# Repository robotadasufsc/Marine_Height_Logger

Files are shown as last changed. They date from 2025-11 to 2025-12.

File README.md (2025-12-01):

# 🌊 Marine Height Logger (LidarBox)






**Desenvolvido por:** Robota da UFSC

## 📖 Visão Geral

O **Marine Height Logger** é um instrumento oceanográfico de baixo custo projetado para registrar a variação de altura da superfície da água (ondas e marés). O sistema utiliza tecnologia **LiDAR** para medir a distância até a água, correlacionando esses dados com posicionamento global (**GPS**) e dados inerciais (**IMU**) para compensar o movimento da boia ou embarcação (Heave/Pitch/Roll).

O firmware foi otimizado para alta performance de escrita, utilizando um **buffer de saída** para salvar dados em lotes no cartão SD, minimizando a latência e evitando gargalos de I/O.

---

## 🛠️ Hardware e Eletrônica

### 1. Lista de Componentes (BOM)

| Componente | Modelo | Função | Protocolo |
| :--- | :--- | :--- | :--- |
| **MCU** | Arduino ProMicro (ATmega32u4) | Processamento Central | - |
| **LiDAR** | Benewake TF02-Pro *ou* SF11 | Distância (Altura) | I²C (Endereço `0x10`) |
| **GPS** | GlobalSat EM-506 | Tempo e Posição | Serial (UART) |
| **IMU** | Pololu MinIMU-9 v5 (LSM6) | Acelerômetro/Giroscópio | I²C |
| **Storage** | SparkFun SD Breakout | Datalogging | SPI |
| **Debug** | LED Genérico | Status Visual | Digital (Pino 5) |

> [!WARNING]
> **Atenção com o LiDAR TF02-Pro:** Este sensor vem de fábrica configurado para Serial. É **obrigatório** reconfigurá-lo para I²C (endereço `0x10`) utilizando o software do fabricante antes da montagem final.

### 2. Pinagem (Conexões)

Baseado na versão atual do firmware (`src/main.cc`):

| Periférico | Pinos Módulo | Pino Arduino | Observação |
| :--- | :--- | :--- | :--- |
| **I²C Bus** | SDA / SCL | **D2 / D3** | LiDAR e IMU compartilham este barramento |
| **GPS** | RX / TX | **TX0 / RX1** | Serial Hardware |
| **SD Card** | CS | **D10** | Chip Select |
| **SD Card** | MOSI | **D16** | SPI MOSI |
| **SD Card** | MISO | **D14** | SPI MISO |
| **SD Card** | SCK | **D15** | SPI Clock |
| **LED Debug** | Anodo (+) | **D5** | LED externo de status |

---

## 🚥 Tabela de Diagnóstico (LEDs)

O sistema não possui tela (headless). O status é comunicado através do **LED Externo (Pino 5)** e do **LED RX interno**, que piscam em sincronia.

### ✅ Status Normal
* **10 Piscadas Rápidas:** Boot concluído com sucesso. Todos os sensores foram detectados e o arquivo de log foi criado.
* **Aceso/Piscando durante operação:** Indica atividade de escrita no buffer ou no cartão SD.

### ❌ Códigos de Erro (Loop Infinito)
Se o sistema falhar durante a inicialização, ele entrará em um loop infinito, piscando o código de erro repetidamente (ciclos de 300ms).

| Nº Piscadas | Código Interno | Significado | Solução Provável |
| :---: | :--- | :--- | :--- |
| **2x** | `ERR_NO_LIDAR` | **LiDAR não encontrado** | Verifique cabos I²C (D2/D3) e alimentação (5V). Confirme o endereço `0x10`. |
| **3x** | `ERR_NO_GPS_LOCK` | **Falha de GPS** | O GPS não respondeu aos comandos iniciais ou baud rate incorreto. |
| **4x** | `ERR_IMU_FAIL` | **Falha no IMU** | O acelerômetro (LSM6) não foi detectado no barramento I²C. |
| **5x** | `ERR_SD_FAIL` | **Falha Física no SD** | Cartão não inserido, mal contatado ou formato inválido. |
| **6x** | `ERR_SD_CREATE_FAIL`| **Erro de Arquivo** | Cartão detectado, mas não foi possível criar o arquivo `LOG_xxxx.CSV` (Cartão cheio?). |

---

## 💾 Detalhes do Firmware e Dados

### Arquivos de Log
O sistema cria arquivos sequenciais na raiz do cartão:
* `LOG_0000.CSV`
* `LOG_0001.CSV`
* ...

### Estrutura do CSV
O arquivo contém as seguintes colunas separadas por tabulação ou vírgula:
1. `gmt_date` / `gmt_time` (Data/Hora GPS)
2. `num_sats` (Qualidade do sinal)
3. `longitude` / `latitude` / `altitude`
4. `laser_altitude_cm` (Leitura bruta do LiDAR)
5. `tilt_deg` (Inclinação calculada)
6. `accel_x/y/z` (Dados brutos do acelerômetro)
7. `gyro_x/y/z` (Dados brutos do giroscópio)

### Segurança de Dados (Buffer)
Para economizar tempo de processamento, o sistema mantém os dados em RAM e realiza a escrita física no cartão SD (**flush**) apenas a cada **20 linhas de medição**.

> [!CAUTION]
> **Ao desligar o equipamento:** Após a última atividade intensa do LED, aguarde cerca de 3 a 5 segundos antes de remover a energia. Isso garante que o último bloco de 20 linhas foi salvo corretamente no cartão, evitando corrupção do arquivo.

### Resiliência (Watchdog I²C)
O código implementa `Wire.setWireTimeout(3000, true)`. Isso impede que o microcontrolador trave completamente caso um sensor I²C (como o IMU ou LiDAR) pare de responder ou desconecte durante a operação.

---

## 🚀 Como Compilar e Enviar

Este projeto utiliza **PlatformIO**.

1. **Clone o repositório:**
   ```bash
   git clone [https://github.com/seu-usuario/Marine_Height_Logger.git](https://github.com/seu-usuario/Marine_Height_Logger.git)
   
2. **Instale as dependências (automático via platformio.ini):**

* SD
* TinyGPSPlus
* LSM6 (Pololu)

3. **Compile e faça o upload:**
    ```Bash
    pio run --target upload

---

##📝 Licença

Este projeto está licenciado sob a EPL-2.0.

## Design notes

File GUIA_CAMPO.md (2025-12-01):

# 📋 Guia de Operação em Campo: Marine Height Logger

Este documento contém instruções rápidas para operação, diagnóstico e segurança dos dados durante a utilização do equipamento em campo.

## 1. Checklist Pré-Operação
Antes de lacrar a caixa ou lançar o equipamento:

- [ ] **Cartão SD:** Inserido corretamente e formatado (FAT16/FAT32).
- [ ] **LiDAR:** Lentes limpas (sem sal, poeira ou obstruções).
- [ ] **Parafusos:** Verificar se todos os parafusos e velcro estão firmes.
- [ ] **Bateria:** Carga verificada.

---

## 2. Procedimento de Inicialização

1. **Ligar:** Alterne o botão para ligado.
2. **Aguardar:** O sistema leva alguns segundos para energizar o GPS e sensores.
3. **Confirmação Visual (LED):**Desconecte
   - O sistema deve emitir **10 piscadas rápidas**.
   - **Significado:** Boot OK + Sensores Detectados + Arquivo `.CSV` criado com sucesso.
4. **Aguardando GPS:** O LED piscará a cada 5 segundos esperando a conexão com os satelites, poderá levar de 30 segundos a 3 minutos. passado esse periodo reinicie e tente novamente. para o fix com os satélites tente deixá-lo em um local aberto e com o sensor gps lateral virado para cima.
5. **Operação:** O LED passará a piscar periodicamente(a cada 1 segundo), indicando que o buffer está enchendo e os dados estão sendo processados.

---

## 3. Procedimento de Desligamento (⚠️ CRÍTICO)

> **Risco de Perda de Dados**
> O sistema utiliza um *buffer* de escrita e só salva fisicamente no cartão SD a cada **20 segundos**. Cortar a energia abruptamente pode corromper o arquivo atual.

1. Observe o LED de status (externo).
2. Após uma sequência de piscadas (atividade de escrita).
3. Alterne o botão para desligado com segurança.

---

## 🆘 Diagnóstico de Erros (LED em Loop)

Se o LED entrar em um padrão repetitivo (pisca X vezes, pausa, repete), consulte a tabela abaixo:

| Piscadas | Componente Falho | Ação Corretiva |
| :---: | :--- | :--- |
| **2x** | **LiDAR** | Sensor não detectado. Verifique cabos SDA/SCL e alimentação. Confirme se está no endereço `0x10`. |
| **3x** | **GPS** | GPS não responde. Verifique cabos TX/RX ou se o módulo está queimado. |
| **4x** | **IMU** | Acelerômetro travado. Verifique conexão I²C com o Pololu MinIMU-9. |
| **5x** | **Cartão SD** | Cartão ausente ou mal encaixado no slot. |
| **6x** | **Erro de Arquivo** | Falha ao criar arquivo `LOG_xxxx.CSV`. Cartão pode estar cheio, protegido (trava física) ou corrompido. |

Tentativas de reparo:
* Ligue e desligue o equipamemto algumas vezes dando um intervalo de 1 segundo mínimo entre cada desligameto.
* Tente iniciar o equipamento sem o cartao SD, deixe entrar no loop de erro, desligue, reinsira o cartão e ligue novamente.
* Tente outras combinações desses métodos. 

---

## 📝 Notas Técnicas
* **Arquivos:** O sistema gera nomes sequenciais (`LOG_0000.CSV`, `LOG_0001.CSV`...). Ele **nunca** sobrescreve arquivos antigos.
* **Sinal de GPS:** Em dias nublados ou locais obstruídos, o GPS pode demorar para obter o *Fix*. O sistema gravará `NaN` ou `INVALID` nas colunas de GPS, mas continuará registrando dados do LiDAR e IMU normalmente.
* **Watchdog:** Se um sensor I²C travar durante a operação, o sistema tentará reiniciar o barramento automaticamente após 3 segundos (timeout), evitando o congelamento total do logger.

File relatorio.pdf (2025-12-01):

# 📄Relatório de Melhorias: Marine Height Logger (LidarBox)

Data: Dezembro/2025
Status: Finalizado

# 1. Evolução da Eletrônica e Potência

Para aumentar a estabilidade do sistema e evitar quedas de tensão (brownouts) críticas para a gravação no cartão SD, o sistema de energia foi totalmente reformulado:

Microcontrolador (5V): Substituição do Arduino Pro Micro 3.3V pela versão de 5V. Isso garante níveis lógicos mais estáveis e compatibilidade direta com a maioria dos periféricos, eliminando problemas de conversão de nível lógico.
Gerenciamento de Energia (BMS): Integração de um módulo BMS (Battery Management System) dedicado. Ele gerencia a carga e descarga, protegendo a célula contra sobrecarga, curto-circuito e descarga profunda, além de garantir uma tensão de saída estável para o sistema.
Bateria 18650: Padronização para célula Li-ion 18650. O novo suporte (holder) permite a substituição rápida da bateria em campo sem a necessidade de ferramentas, aumentando a autonomia operacional.

# 2. Sensores e Hardware

Os módulos principais foram atualizados para versões mais eficientes, precisas e compactas:

LiDAR (Benewake TF02): Implementação do sensor Benewake TF02, configurado para comunicação via protocolo I²C. Este modelo oferece maior robustez contra interferência solar e leituras mais estáveis sobre a superfície da água comparado ao modelo anterior.
IMU (MinIMU-9 v6): Atualização para o módulo Pololu MinIMU-9 v6. Este módulo integra sensores de última geração (LSM6DSO para acelerômetro/giroscópio e LIS3MDL para magnetômetro), proporcionando uma precisão superior na compensação de movimentos (tilt/roll) da embarcação ou drone.
GPS (GP-735T): Substituição pelo módulo GP-735T. Escolhido pelo seu fator de forma extremamente compacto e capacidade de aquisição rápida de satélites (Fast Time-to-Fix).
PCB Dedicada: Todo o circuito, anteriormente prototipado em fios, foi migrado para uma Placa de Circuito Impresso (PCB) personalizada. Isso permite a fixação rígida de quase todos os módulos, eliminando a "fiação aérea" e aumentando drasticamente a resistência mecânica contra as vibrações dos drones.

# 3. Mecânica e Interface de Usuário (UX)

A carcaça foi completamente remodelada focando na ergonomia do operador e no feedback visual imediato:

Acoplamento Universal: Novo sistema de fita com velcro de fixação para drones, facilitando o balanceamento do centro de gravidade e garantindo segurança durante o voo.
Display de Bateria: Inclusão de um display dedicado para verificação de tensão da bateria. Botão de Checagem: Adicionado um botão momentâneo para ligar o display apenas quando necessário, economizando energia.
Controles Externos:
Botão Mestre (On/Off): Interruptor de fácil acesso para ligar e desligar o sistema.
LED de Debug Externo: Permite o diagnóstico de erros e confirmação de gravação sem a necessidade de abrir o case à prova d'água.

# 4. Documentação e Código

O projeto foi organizado para facilitar a manutenção futura e o uso por novos membros da equipe:

Repositório: Código fonte versionado e centralizado no GitHub.
Estrutura: Melhor detalhada no README.md no GitHub do projeto.
Operação: Detalhado no arquivo GUIA_CAMPO , trata-se de um manual simplificado focado na operação prática e tabelas de erro para impressão e uso in loco.

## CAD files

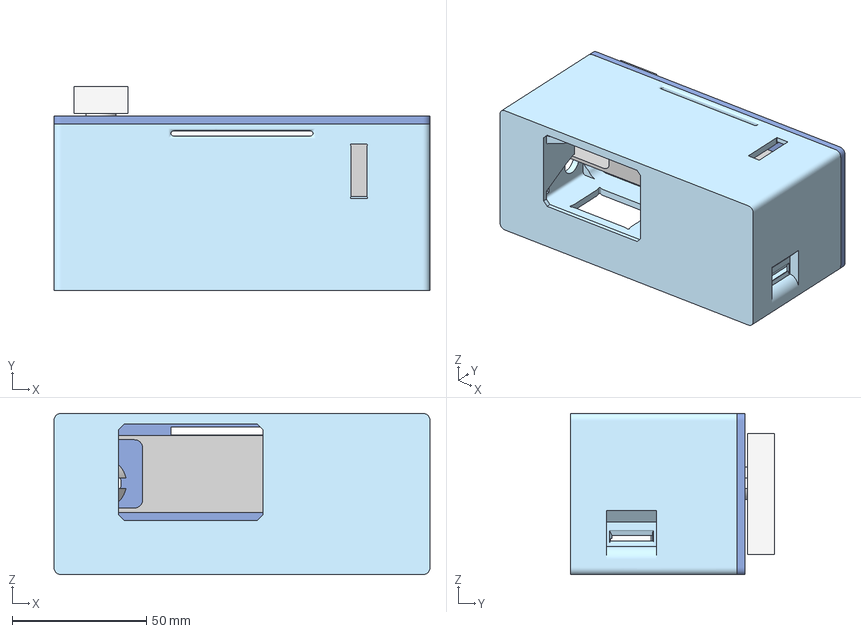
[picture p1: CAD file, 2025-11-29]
hardware/3d_model/stl/MHL.3mf
140.0 x 76.0 x 60.0 mm
caixa
suporte_bateria
espacador
tampa

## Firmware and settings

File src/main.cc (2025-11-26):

// Program to talk to a GPS module (GlobalSat EM-506 GPS or lightware SF-11 laser rangefinder), an IMU
// (Pololu MinIMU-9 v5), and log to SparkFun SDcard board.

// Adapted from https://doi.org/10.3389/fmars.2017.00366

#include <SD.h>
#include <Wire.h> // Necessário incluir explicitamente para usar setWireTimeout

#include "lidar/common.h"
#include "gps/common.h"
#include "debug.h"
#include "imu.h"

// SDcard SPI pins
#define SPI_CS  10

// Debug LED pin
#define DEBUG_LED_PIN 5

// Defina uma variável global ou estática
static int contador_flush = 0;




enum ErrorType {
	ERR_NO_LIDAR = 2,
	ERR_NO_GPS_LOCK,
	ERR_IMU_FAIL,
	ERR_SD_FAIL,
	ERR_SD_CREATE_FAIL
};

// the logging file
static File logfile;

/**
 * Captures the execution of the program and report the status. The report is done through the RX_LED by blinking.
 * 
 * The number of flashes in each cycle encodes the error.
 * 
 * \param code The number of times the LED will flash each cycle.
 */
__ATTR_NORETURN__ void lock_and_report_error(size_t code) {
	while(1) {  // lock it up, blinking forever
		for(size_t i = 0; i < code; i++) {
			digitalWrite(DEBUG_LED_PIN, HIGH);
			digitalWrite(LED_BUILTIN_RX, HIGH);
			TXLED0;
			delay(300);
			digitalWrite(DEBUG_LED_PIN, LOW);
			digitalWrite(LED_BUILTIN_RX, LOW);
			TXLED1;
			delay(300);
		}
		TXLED0;
		delay(2000);
	}
}

#ifdef DEBUG_TO_SERIAL
size_t get_free_ram_size() {
	extern size_t __heap_start, *__brkval;
	size_t v;
	return &v - (__brkval == 0 ? &__heap_start : __brkval);
}
#endif

/**
 * Set the current date and time based on the last GPS result.
 * 
 * \param[out] date The date.
 * \param[out] time The time.
 */
void fat_datetime_callback(uint16_t *date, uint16_t *time) {
  if(gps.date.isValid())
	  *date = FAT_DATE(gps.date.year(), gps.date.month(), gps.date.day());

  if(gps.time.isValid())
  	*time = FAT_TIME(gps.time.hour(), gps.time.minute(), gps.time.second());
}

void setup() {
	// We start the serial object even without debug, or the IMU doesn't work
	Serial.begin(115200);

	pinMode(DEBUG_LED_PIN, OUTPUT);

#ifdef DEBUG_TO_SERIAL
	// Careful with this next line, if computer isn't attatched it will hang
	while(!Serial)  // loop while ProMicro takes a moment to get itself together
		if(millis() > 6000)  // give up waiting for USB cable plugin after 6 sec
			break;

	DEBUG(F("Free RAM: "));
	DEBUGLN(get_free_ram_size());
#else 
	delay(1000);
#endif

	if(!setup_lidar()) {
		DEBUGLN(F("LiDAR error. Halting."));
		lock_and_report_error(ERR_NO_LIDAR);
	}

	if(!setup_gps()) {
		DEBUGLN(F("GPS error. Halting."));
		lock_and_report_error(ERR_NO_GPS_LOCK);
	}

	if(!setup_imu()) {
		DEBUGLN(F("IMU error. Halting"));
		lock_and_report_error(ERR_IMU_FAIL);
	}
	imu.enableDefault();

	// Se o cabo do IMU falhar, o Arduino nao trava infinitamente
    Wire.setWireTimeout(3000, true); 

	// see if the card is present and can be initialised
	if(!SD.begin(SPI_CS)) {
		DEBUGLN(F("SD card error. Halting."));
		lock_and_report_error(ERR_SD_FAIL);
	}

	consume_gps();

	// set SD file date time callback function
	SdFile::dateTimeCallback(fat_datetime_callback);

	// create a new file
	char filename[] = "LOG_0000.CSV";
	for(u16 i = 0; i < 10000; i++) {
		filename[4] = i / 1000 + '0';
		filename[5] = (i % 1000) / 100 + '0';
		filename[6] = (i % 100) / 10 + '0';
		filename[7] = i % 10 + '0';

		DEBUG(filename);
		DEBUG(' ');

		// Only open a new file if it doesn't exist
		if(!SD.exists(filename)) {
			// We consume the GPS data so we can set the creation date of the file
			logfile = SD.open(filename, FILE_WRITE);
			DEBUGLN(F("is available"));

			break;
		}
		DEBUGLN(F("already exists."));
	}

	wakeful_delay(500);  // give it a chance to catch up before testing if it's ok.
	if(!logfile) {
		DEBUGLN(F("ERROR: couldn't create log file. Halting."));
		lock_and_report_error(ERR_SD_CREATE_FAIL);
	}

	logfile.println(F("# GPS and Laser Rangefinder logging with Pro Micro Arduino 3.3v"));
	logfile.println(F("# units:  accel=1g  gyro=deg/sec"));

	logfile.print(F("#gmt_date\tgmt_time\tnum_sats\tlongitude\tlatitude\t"));
	logfile.print(F("gps_altitude_m\tSOG_kt\tCOG\tHDOP\tlaser_altitude_cm\t"));
	logfile.println(F("tilt_deg\taccel_x\taccel_y\taccel_z\tgyro_x\tgyro_y\tgyro_z"));
	logfile.flush();

	// Should we wait a while for GPS to get a fix?
	wakeful_delay(2000);

	// Signal we are ready by blinking ten times
	for(int i = 0; i < 10; i++) {
		digitalWrite(LED_BUILTIN_RX, LOW);
		digitalWrite(DEBUG_LED_PIN, LOW);
		TXLED1;
		wakeful_delay(100);
		digitalWrite(LED_BUILTIN_RX, HIGH);
		digitalWrite(DEBUG_LED_PIN, HIGH);
		TXLED0;
		wakeful_delay(100);
	}
}

#define __WRITE_GPS_MEASURE__(gps, stream, property, accessor) { \
	if(gps.property.isValid()) stream.print(gps.property.accessor()); \
	else stream.print(F("NaN")); \
	stream.print(F("\t")); \
}

/**
 * \param stream         The `Stream` to write to.
 * \param lidar_distance The distance read by the lidar, in centimetres.
 * \param imu_results    The results returned by the innertial mesurement unit.
 */
void write_data_line(Stream &stream, uint16_t lidar_distance, const struct IMUData &imu_results, bool report_writing = false) {
	if(report_writing) {
		TXLED1;
		digitalWrite(DEBUG_LED_PIN, HIGH);
	}// The Tx LED is not tied to a normally controlled pin so we use this macro

	if(gps.date.isValid()) {
		u16 year = gps.date.year();
		u8 month = gps.date.month();
		u8 day = gps.date.day();
		stream.print(year);
		stream.print(F("/"));
		if(month < 10) stream.print(F("0"));
		stream.print(month);
		stream.print(F("/"));
		if(day < 10) stream.print(F("0"));
		stream.print(day);
	} else {
		stream.print(F("INVALID"));
	}
	stream.print(F("\t"));
	if(gps.time.isValid()) {
		u8 hour = gps.time.hour();
		u8 minute = gps.time.minute();
		u8 second = gps.time.second();
		if(hour < 10) stream.print(F("0"));
		stream.print(hour);
		stream.print(F(":"));
		if(minute < 10) stream.print(F("0"));
		stream.print(minute);
		stream.print(F(":"));
		if(second < 10) stream.print(F("0"));
		stream.print(second);
	} else {
		stream.print(F("INVALID"));
	}
	stream.print(F("\t"));

	stream.print(gps.satellites.value());
	stream.print(F("\t"));
	if(gps.location.isValid()) {
		// The latitude and longitude floating point values are restricted to 32bit precision; so a total of 7 or 8
		// significant digits including those before the decimal point (1e-5 * 1852 * 60 = 1.11 meters)
		stream.print(gps.location.lng(), 6);
		stream.print(F("\t"));
		stream.print(gps.location.lat(), 6);
	} else {
		stream.print(F("NaN\tNaN"));
	}
	stream.print(F("\t"));
	
	__WRITE_GPS_MEASURE__(gps, stream, altitude, meters);
	__WRITE_GPS_MEASURE__(gps, stream, speed, knots);
	__WRITE_GPS_MEASURE__(gps, stream, course, deg);
	__WRITE_GPS_MEASURE__(gps, stream, hdop, value);
	
	if(lidar_distance == -1) stream.print(F("NaN"));
	else stream.print(lidar_distance);
	stream.print(F("\t"));
	
	stream.print(imu_results.tilt_deg, 2);
	stream.print(F("\t"));
	stream.print(imu_results.accel_x, 4);
	stream.print(F("\t"));
	stream.print(imu_results.accel_y, 4);
	stream.print(F("\t"));
	stream.print(imu_results.accel_z, 4);
	stream.print(F("\t"));
	stream.print(imu_results.gyro_x, 3);
	stream.print(F("\t"));
	stream.print(imu_results.gyro_y, 3);
	stream.print(F("\t"));
	stream.print(imu_results.gyro_z, 3);
	stream.println();

	if(report_writing) {
		TXLED0;
		digitalWrite(DEBUG_LED_PIN, LOW);
	}
}

#undef __WRITE_GPS_MEASURE__

void loop(void) {
	// IMU
	IMUData imu_results;
	
	uint16_t lidar_distance = get_lidar_distance_cm();

	// get GPS string
	consume_gps();

	// Output row without GPS data every 5 sec if no fix
	if(!gps.date.isUpdated() || gps.location.age() > 1750) {
		unsigned long first_detected = millis();
		unsigned long next_signal = 5000;

		while(!gps.date.isUpdated() || gps.location.age() > 1750) {
			consume_gps();
			unsigned long delta_t = millis() - first_detected;

			if(delta_t > next_signal) {
				lidar_distance = get_lidar_distance_cm();

				get_imu_readings(imu_results);

#ifdef DEBUG_DATA
				// Printout to USB-serial
				if(DEBUG_STREAM)
					write_data_line(DEBUG_STREAM, lidar_distance, imu_results);
#endif
				write_data_line(logfile, lidar_distance, imu_results, true);
				logfile.flush();

				next_signal += 5000;
			}
		}
	}

	get_imu_readings(imu_results);

	// update gps data available scan again to clear the decks
	consume_gps();


#ifdef DEBUG_DATA
	// Printout to USB-serial
	if(DEBUG_STREAM)
		write_data_line(DEBUG_STREAM, lidar_distance, imu_results);
#endif

	// write to SD card
	write_data_line(logfile, lidar_distance, imu_results, true);
	//logfile.flush();
	// Só salva fisicamente no cartão a cada 20 linhas
	if(contador_flush >= 20) {
		logfile.flush();
		contador_flush = 0;
	} else {
		contador_flush++;
	}
}

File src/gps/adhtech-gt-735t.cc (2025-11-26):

#ifdef GPS_ADHTECH_GT_735T

#include "./common.h"
#include "../debug.h"

TinyGPSPlus gps;

// Função auxiliar para enviar comandos UBX de forma segura
// Evita problemas com caracteres nulos (\x00) dentro de strings
void sendUBX(const uint8_t *progmem_command, size_t len) {
    for (size_t i = 0; i < len; i++) {
        Serial1.write(pgm_read_byte(progmem_command + i));
    }
    Serial1.flush(); // Garante o envio antes de continuar
}

// Definição dos comandos em PROGMEM para economizar RAM
const uint8_t DISABLE_GLL[] PROGMEM = {0xB5,0x62,0x06,0x01,0x08,0x00,0xF0,0x01,0x01,0x00,0x01,0x01,0x01,0x01,0x05,0x3A};
const uint8_t DISABLE_GSA[] PROGMEM = {0xB5,0x62,0x06,0x01,0x08,0x00,0xF0,0x02,0x01,0x00,0x01,0x01,0x01,0x01,0x06,0x41};
const uint8_t DISABLE_GSV[] PROGMEM = {0xB5,0x62,0x06,0x01,0x08,0x00,0xF0,0x03,0x01,0x00,0x01,0x01,0x01,0x01,0x07,0x48};
const uint8_t DISABLE_VTG[] PROGMEM = {0xB5,0x62,0x06,0x01,0x08,0x00,0xF0,0x05,0x01,0x00,0x01,0x01,0x01,0x01,0x09,0x56};
const uint8_t DISABLE_ZDA[] PROGMEM = {0xB5,0x62,0x06,0x01,0x08,0x00,0xF0,0x08,0x00,0x00,0x00,0x00,0x00,0x00,0x07,0x5B};
const uint8_t ENABLE_GGA[]  PROGMEM = {0xB5,0x62,0x06,0x01,0x08,0x00,0xF0,0x00,0x01,0x01,0x01,0x01,0x01,0x01,0x05,0x38};
const uint8_t ENABLE_RMC[]  PROGMEM = {0xB5,0x62,0x06,0x01,0x08,0x00,0xF0,0x04,0x01,0x01,0x01,0x01,0x01,0x01,0x09,0x54};
const uint8_t SAVE_CONFIG[] PROGMEM = {0xB5,0x62,0x06,0x09,0x0C,0x00,0x00,0x00,0x00,0x00,0xFF,0xFF,0x00,0x00,0x00,0x00,0x00,0x00,0x19,0x80};

// Forward declaration
void wakeful_delay(unsigned long ms);
void consume_gps();

bool setup_gps() {
    // GPS is on the ProMicro's UART (Serial1)
    // RX: pin 0; TX: pin 1
    Serial1.begin(9600);
    
    // CORREÇÃO: Limpar buffer inicial
    delay(10);
    while(Serial1.available()) Serial1.read();

    // Verificação real de hardware: Espera até receber pelo menos 1 byte do GPS
    // Isso confirma que o GPS está ligado e transmitindo
    unsigned long start_wait = millis();
    bool gps_detected = false;
    
    DEBUGLN(F("Aguardando dados do GPS..."));
    
    while (millis() - start_wait < 5000) { // Espera até 5 segundos por dados
        if (Serial1.available()) {
            gps_detected = true;
            break;
        }
    }

    if (!gps_detected) {
		return false;
        DEBUGLN(F("ALERTA: GPS nao enviou dados nos primeiros 5s (Verifique cabos RX/TX)"));
        // Não retornamos false aqui para tentar configurar mesmo assim, 
        // mas é um forte indicativo de problema elétrico.
    }

    // Configuração do GPS
    // Usamos sendUBX e wakeful_delay para não travar o buffer

    sendUBX(DISABLE_GLL, 16);
    wakeful_delay(100); // CORREÇÃO: wakeful_delay em vez de delay

    sendUBX(DISABLE_GSA, 16);
    wakeful_delay(100);

    sendUBX(DISABLE_GSV, 16);
    wakeful_delay(100);

    sendUBX(DISABLE_VTG, 16);
    wakeful_delay(100);

    sendUBX(DISABLE_ZDA, 16);
    wakeful_delay(100);

    sendUBX(ENABLE_GGA, 16);
    wakeful_delay(100);

    sendUBX(ENABLE_RMC, 16);
    wakeful_delay(100);
    
    // Save configuration
    sendUBX(SAVE_CONFIG, 20);
    wakeful_delay(250);

    return true;
}

void wakeful_delay(unsigned long ms) {
    unsigned long limit = millis() + ms;
    do {
        consume_gps();
    } while(millis() < limit);
}

void consume_gps() {
    // CORREÇÃO: Leitura byte a byte é mais eficiente e segura que buffer de array
    while(Serial1.available() > 0) {
        char c = Serial1.read();
        gps.encode(c);
        
        #ifdef DEBUG_NMEA
        DEBUG_STREAM.write(c);
        #endif
    }
}

#endif

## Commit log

2025-11-26 Led Adicionado e variavel do lidar atualizada
2025-11-26 add contador de linhas para escrita
2025-11-26 Retirei a variavel reduntante lidar_distance
2025-11-26 debug led
2025-11-29 Add 3d model files
    [MHL.3mf]
2025-12-01 Correcao de erros

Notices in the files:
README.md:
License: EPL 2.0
